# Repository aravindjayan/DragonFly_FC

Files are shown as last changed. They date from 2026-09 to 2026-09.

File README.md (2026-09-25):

# DragonFly Flight Controller

DragonFly Flight Controller is an open hardware, low-cost flight controller PCB and experimentation platform for UAV, drone, and embedded systems prototyping. This cost-optimised design uses a two-layer PCB, a budget-conscious bill of materials (BOM), and readily fabricated manufacturing files. Prototype boards were fabricated using the LionCircuits MII service.

The KiCad design targets broad sensor compatibility: it supports most ST LSM6D-series IMUs, while the magnetometer footprint accommodates QMC5883, HMC5883, MMC5983, and IST8310 parts. This makes DragonFly a flexible platform for flight-control experiments, sensor evaluation, and affordable PCB prototyping.

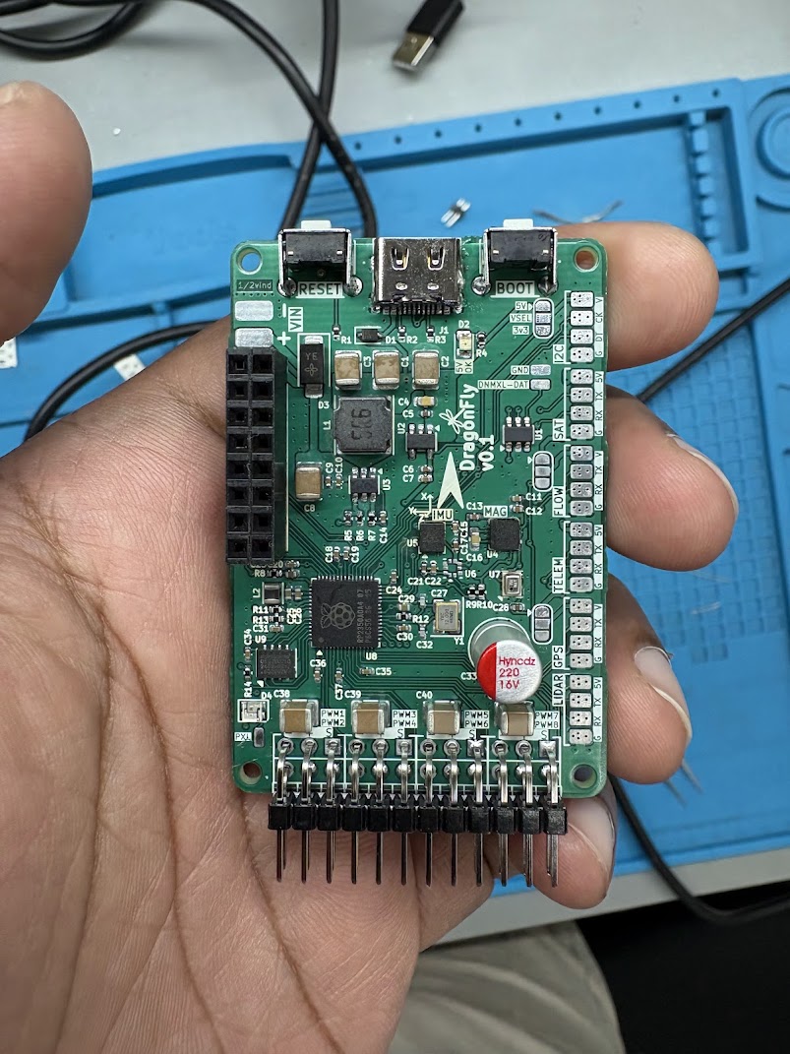
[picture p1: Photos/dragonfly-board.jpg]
Assembled DragonFly flight controller


## Repository contents

- `KiCad/Source/` — editable V0.1 board, hierarchical schematic sheets, and project settings.
- `KiCad/Production/` — PCB and project settings for the released `withRibs` manufacturing revision used to generate the production Gerbers.
- `Manufacturing/Gerbers/` — production Gerber layers, drill files, drill maps, and KiCad job file.
- `Photos/` — photo of the assembled PCB.

## Fabrication

Send all files in `Manufacturing/Gerbers/` to your PCB fabricator as one fabrication package. The set includes front and back copper, solder mask, silkscreen, paste, board outline, plated and non-plated drill files, drill maps, and the Gerber job file. Confirm your fabricator accepts these Gerber formats and review the generated previews before ordering.

The released board includes an external rib frame (`withRibs`) for fabrication. Use the matching board in `KiCad/Production/` when reviewing this manufacturing package. `KiCad/Source/` retains the editable source project from the main V0.1 design directory.

## Opening the design

Open `KiCad/Source/dragonfly_v0_1.kicad_pro` in KiCad to work with the source design. Open `KiCad/Production/Dragonfly_v0-1_Ribs.kicad_pcb` to inspect the exact released manufacturing board.

## Revision notes

The production files are from the V0.1 `withRibs` release. The original release notes describe it as adding an external rib frame for improved fabrication. Review electrical design, clearances, and fabrication outputs independently before manufacturing or flight use.

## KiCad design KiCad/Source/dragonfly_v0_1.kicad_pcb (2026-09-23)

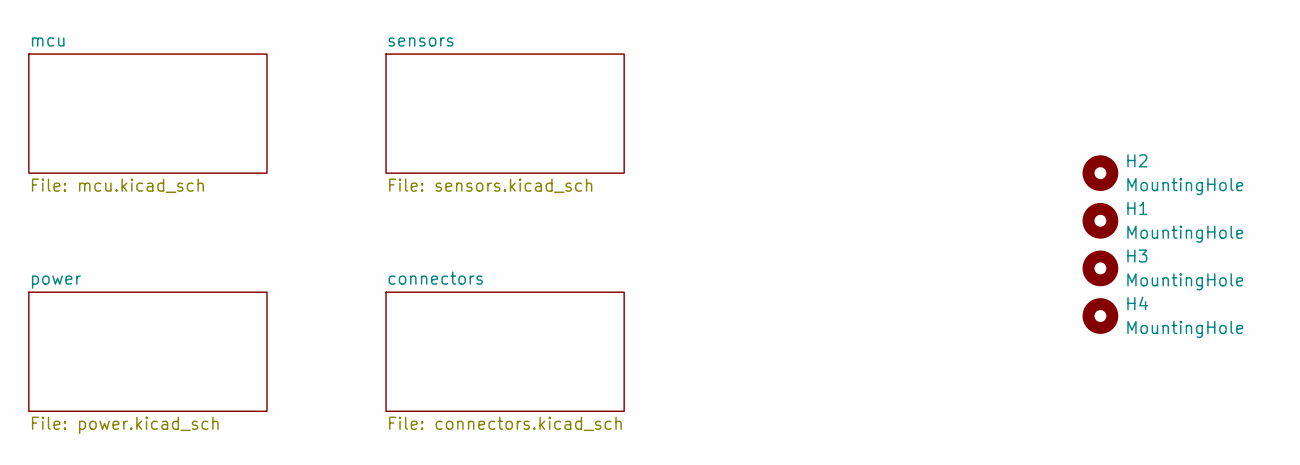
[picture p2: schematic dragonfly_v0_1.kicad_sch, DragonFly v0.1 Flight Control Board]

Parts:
H1, H2, H3, H4: MountingHole; MountingHole_2.2mm_M2_ISO14580

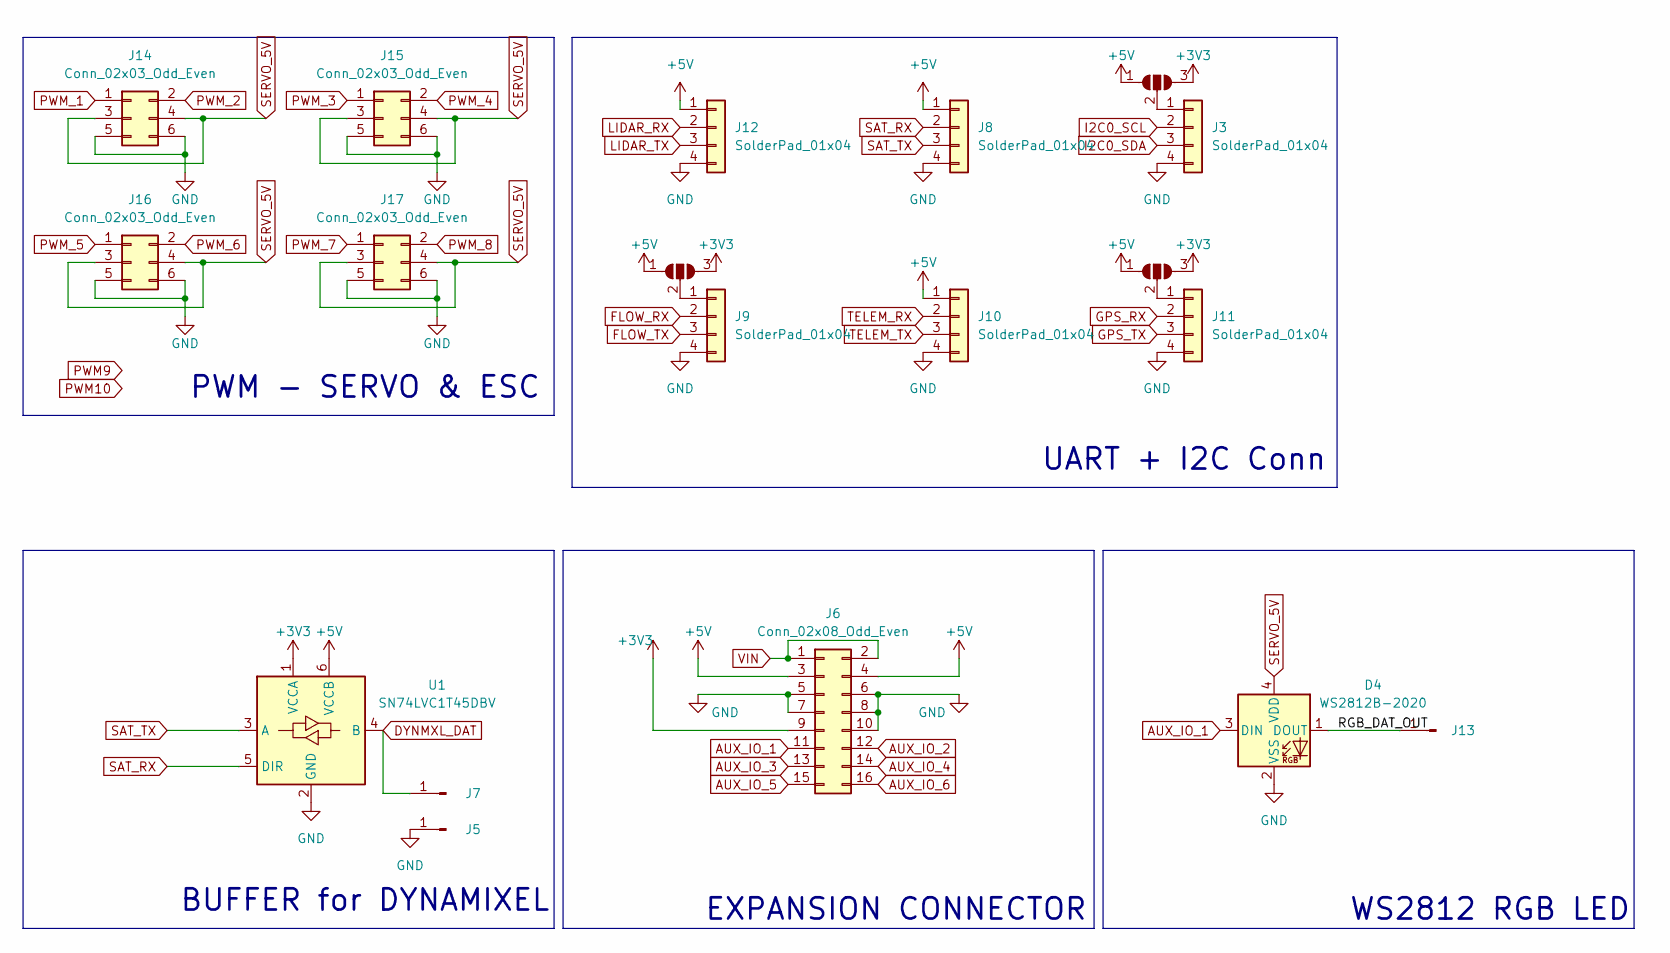
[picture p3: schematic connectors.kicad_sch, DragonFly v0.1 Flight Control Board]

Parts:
D4: WS2812B-2020; LED_WS2812B-2020_PLCC4_2.0x2.0mm
J3, J8, J9, J10, J11, J12: SolderPad_01x04; 4pad_doubleSide_rect_1.7x2mm
J5, J7, J13: SolderPad; SolderWirePad_1x01_SMD_1x2mm
J6: Conn_02x08_Odd_Even; PinSocket_2x08_P2.54mm_Vertical
J14, J15, J16, J17: Conn_02x03_Odd_Even; dragonfly_conn_2x3_graphics
JP1, JP2, JP3: SolderJumper_3_Open; SolderJumper-3_P1.3mm_Open_RoundedPad1.0x1.5mm
U1: SN74LVC1T45DBV; SOT-23-6

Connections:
+3V3: J6.9, JP1.3 (B), JP2.3 (B), JP3.3 (B), U1.1 (VCCA); also elsewhere on the board
+5V: J6.3, J6.4, J8.1, J10.1, J12.1, JP1.1 (A), JP2.1 (A), JP3.1 (A), U1.6 (VCCB); also elsewhere on the board
/connectors/RGB_DAT_OUT: D4.1 (DOUT), J13.1
AUX_IO_1: D4.3 (DIN), J6.11; also elsewhere on the board
AUX_IO_2: J6.12; also elsewhere on the board
AUX_IO_3: J6.13; also elsewhere on the board
AUX_IO_4: J6.14; also elsewhere on the board
AUX_IO_5: J6.15; also elsewhere on the board
AUX_IO_6: J6.16; also elsewhere on the board
DYNMXL_DAT: J7.1, U1.4 (B)
FLOW_RX: J9.2; also elsewhere on the board
FLOW_TX: J9.3; also elsewhere on the board
GND: D4.2 (VSS), J3.4, J5.1, J6.5, J6.6, J6.7, J6.8, J6.10, J8.4, J9.4, J10.4, J11.4, J12.4, J14.5, J14.6, J15.5, J15.6, J16.5, J16.6, J17.5, J17.6, U1.2 (GND); also elsewhere on the board
GPS_RX: J11.2; also elsewhere on the board
GPS_TX: J11.3; also elsewhere on the board
I2C0_SCL: J3.2; also elsewhere on the board
I2C0_SDA: J3.3; also elsewhere on the board
LIDAR_RX: J12.2; also elsewhere on the board
LIDAR_TX: J12.3; also elsewhere on the board
unnamed: J3.1, JP1.2 (C)
unnamed: J9.1, JP2.2 (C)
unnamed: J11.1, JP3.2 (C)
PWM_1: J14.1; also elsewhere on the board
PWM_2: J14.2; also elsewhere on the board
PWM_3: J15.1; also elsewhere on the board
PWM_4: J15.2; also elsewhere on the board
PWM_5: J16.1; also elsewhere on the board
PWM_6: J16.2; also elsewhere on the board
PWM_7: J17.1; also elsewhere on the board
PWM_8: J17.2; also elsewhere on the board
SAT_RX: J8.2, U1.5 (DIR); also elsewhere on the board
SAT_TX: J8.3, U1.3 (A); also elsewhere on the board
SERVO_5V: D4.4 (VDD), J14.3, J14.4, J15.3, J15.4, J16.3, J16.4, J17.3, J17.4; also elsewhere on the board
TELEM_RX: J10.2; also elsewhere on the board
TELEM_TX: J10.3; also elsewhere on the board
VIN: J6.1, J6.2; also elsewhere on the board

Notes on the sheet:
UART + I2C Conn
EXPANSION CONNECTOR
PWM - SERVO & ESC
WS2812 RGB LED
BUFFER for DYNAMIXEL

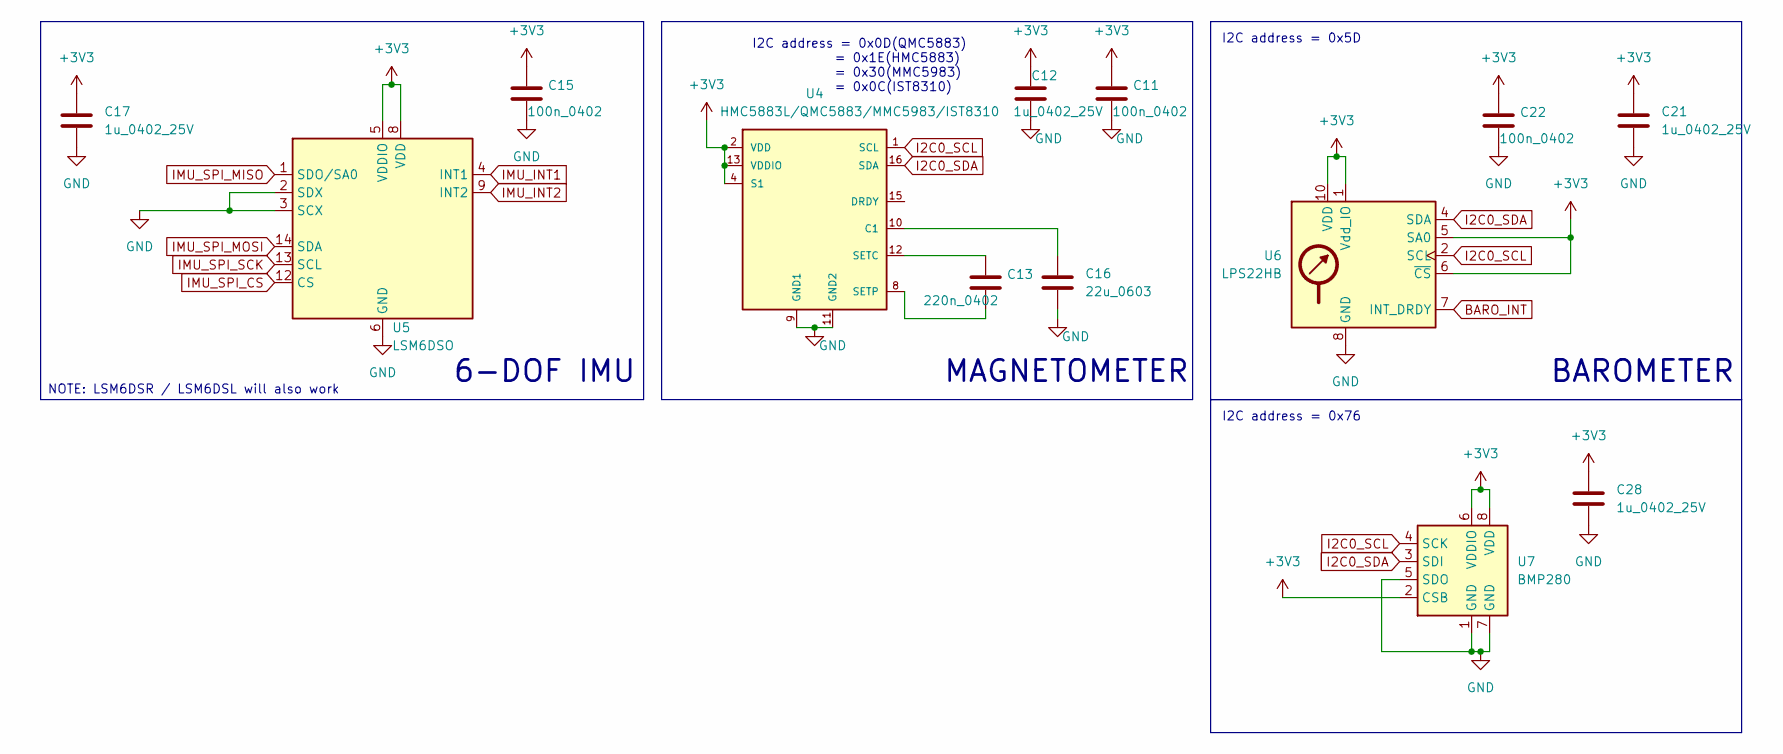
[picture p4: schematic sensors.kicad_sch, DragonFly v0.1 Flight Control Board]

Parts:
C11, C15, C22: 100n_0402; C_0402_1005Metric
C12, C17, C21, C28: 1u_0402_25V; C_0402_1005Metric
C13: 220n_0402; C_0402_1005Metric
C16: 22u_0603; C_0603_1608Metric
U4: HMC5883L/QMC5883/MMC5983/IST8310; HMC5883L
U5: LSM6DSO; LGA-14_3x2.5mm_P0.5mm_LayoutBorder3x4y
U6: LPS22HB; LPS22_HLGA10_SNAPEDA
U7: BMP280; BMP280_Bosch_LGA-8_2x2.5mm_P0.65mm_ClockwisePinNumbering

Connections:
+3V3: C11.1, C12.1, C15.1, C17.1, C21.1, C22.1, C28.1, U4.2 (VDD), U4.4 (S1), U4.13 (VDDIO), U5.5 (VDDIO), U5.8 (VDD), U6.1 (Vdd_IO), U6.5 (SA0), U6.6 (~CS), U6.10 (VDD), U7.2 (CSB), U7.6 (VDDIO), U7.8 (VDD); also elsewhere on the board
BARO_INT: U6.7 (INT_DRDY)
GND: C11.2, C12.2, C15.2, C16.2, C17.2, C21.2, C22.2, C28.2, U4.9 (GND1), U4.11 (GND2), U5.2 (SDX), U5.3 (SCX), U5.6 (GND), U5.7 (GND), U6.3 (GND), U6.8 (GND), U6.9 (GND), U7.1 (GND), U7.5 (SDO), U7.7 (GND); also elsewhere on the board
I2C0_SCL: U4.1 (SCL), U6.2 (SCL), U7.4 (SCK); also elsewhere on the board
I2C0_SDA: U4.16 (SDA), U6.4 (SDA), U7.3 (SDI); also elsewhere on the board
IMU_INT1: U5.4 (INT1)
IMU_INT2: U5.9 (INT2)
IMU_SPI_CS: U5.12 (CS); also elsewhere on the board
IMU_SPI_MISO: U5.1 (SDO/SA0); also elsewhere on the board
IMU_SPI_MOSI: U5.14 (SDA); also elsewhere on the board
IMU_SPI_SCK: U5.13 (SCL); also elsewhere on the board
unnamed: C16.1, U4.10 (C1)
unnamed: C13.1, U4.12 (SETC)
unnamed: C13.2, U4.8 (SETP)

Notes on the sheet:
BAROMETER
NOTE: LSM6DSR / LSM6DSL will also work
I2C address = 0x0D(QMC5883) = 0x1E(HMC5883) = 0x30(MMC5983) = 0x0C(IST8310)
I2C address = 0x76
6-DOF IMU
MAGNETOMETER
I2C address = 0x5D

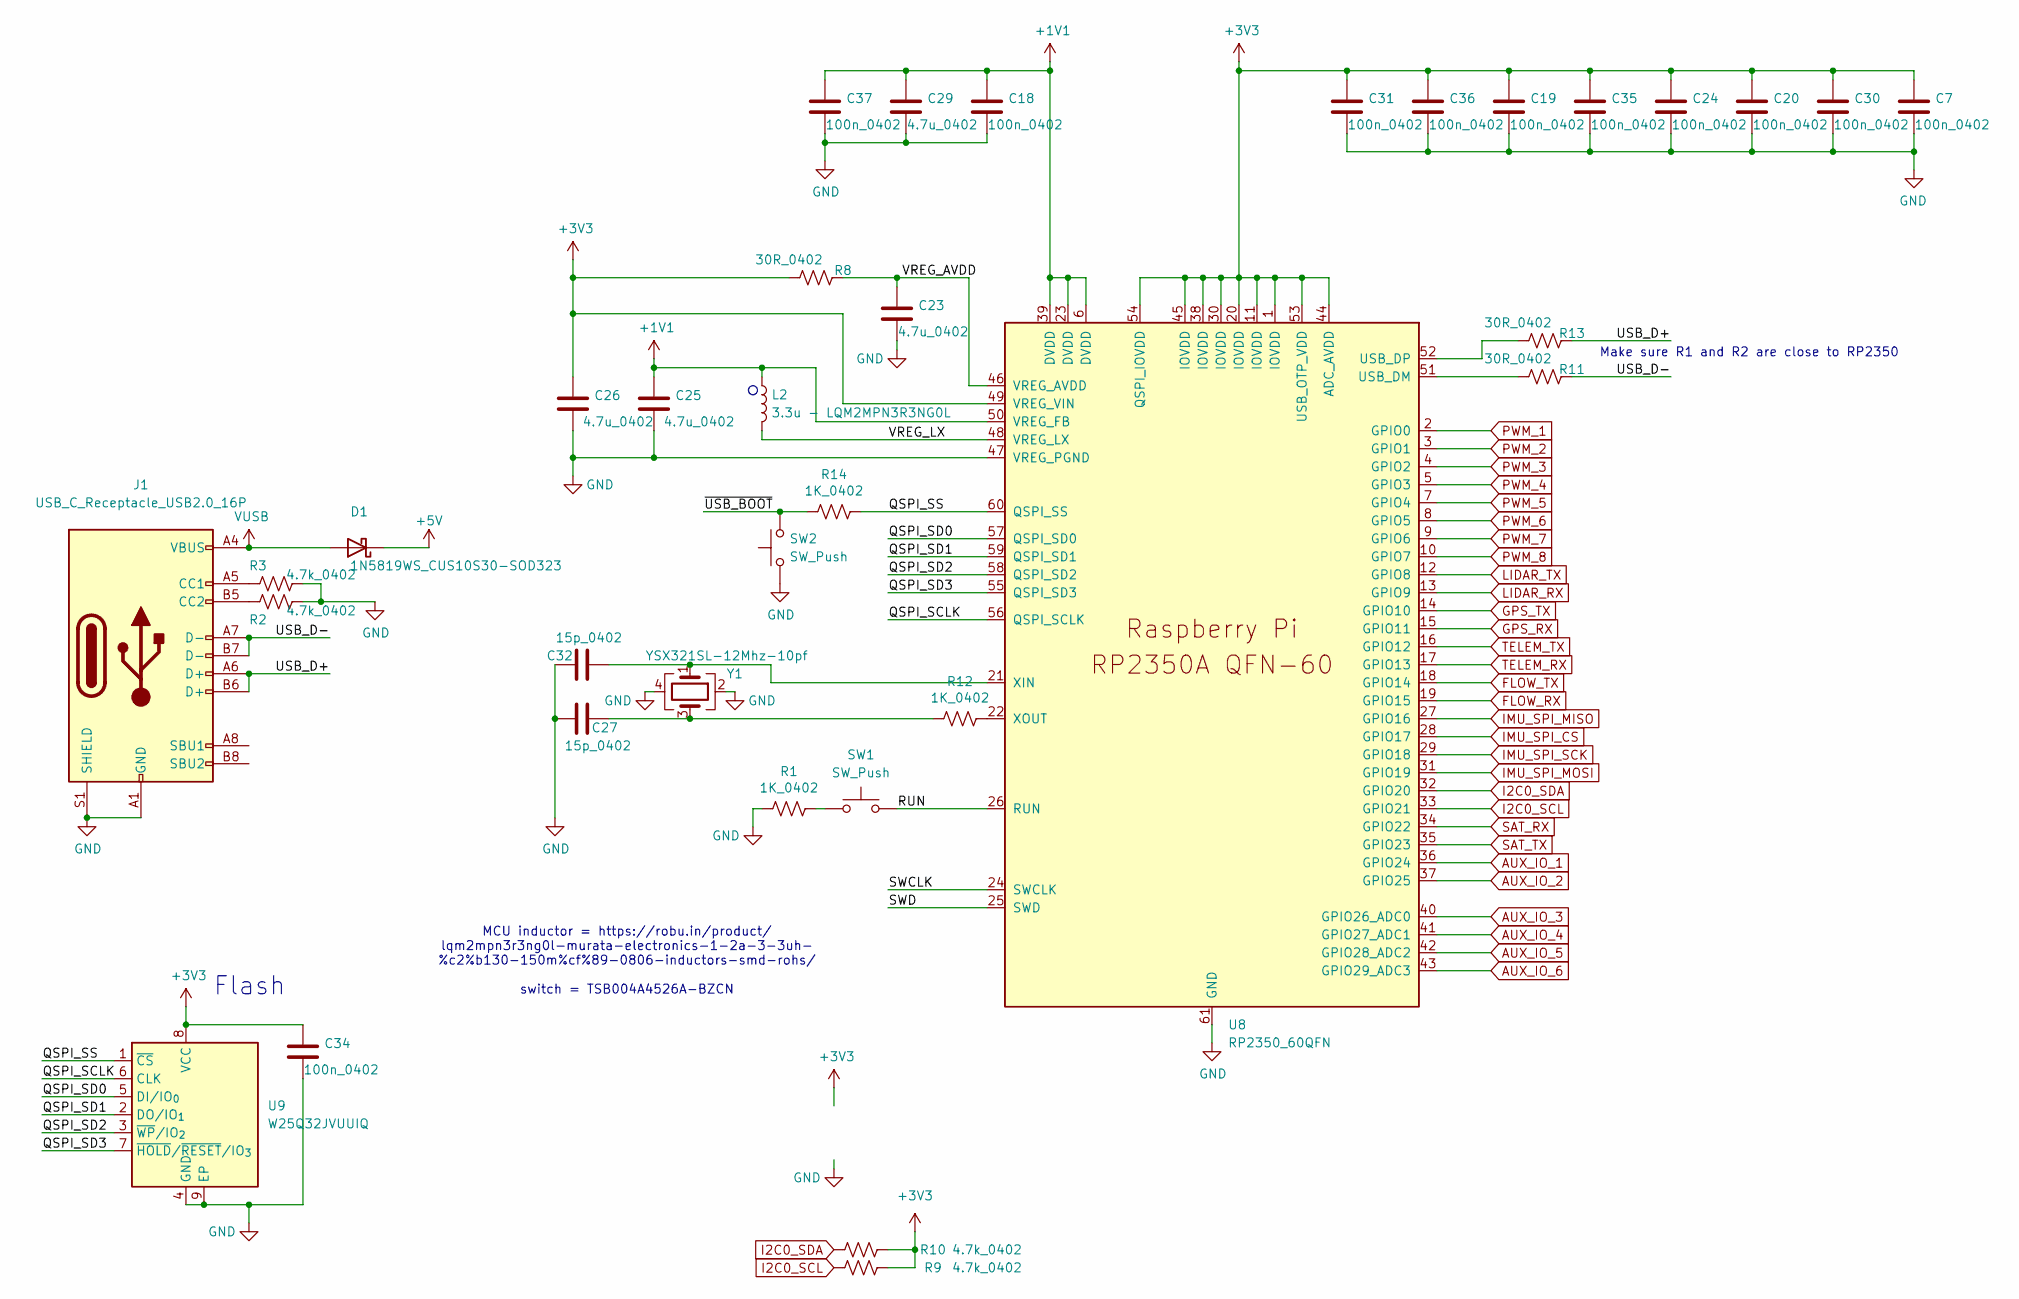
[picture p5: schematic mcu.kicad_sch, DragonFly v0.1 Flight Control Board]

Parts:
C7, C18, C19, C20, C24, C30, C31, C34, C35, C36, C37: 100n_0402; C_0402_1005Metric
C23, C29: 4.7u_0402; C_0402_1005Metric
C25, C26: 4.7u_0402; C_0402_SmallPads
C27, C32: 15p_0402; C_0402_1005Metric
D1: 1N5819WS_CUS10S30-SOD323; D_SOD-323
J1: USB_C_Receptacle_USB2.0_16P; USB_C_Receptacle_XKB_U262-16XN-4BVC11
L2: 3.3u - LQM2MPN3R3NG0L; L_Murata_DFE201610P
R1, R12, R14: 1K_0402; R_0402_1005Metric
R2, R3, R9, R10: 4.7k_0402; R_0402_1005Metric
R8, R11, R13: 30R_0402; R_0402_1005Metric
SW1, SW2: SW_Push; rightAngle_Switch_MJTP1117
U8: RP2350_60QFN; QFN-60-1EP_7x7mm_P0.4mm_EP3.4x3.4mm_ThermalVias_RP2350
U9: W25Q32JVUUIQ; Winbond_USON-8-2EP_3x4mm_P0.8mm_EP0.2x0.8mm
Y1: YSX321SL-12Mhz-10pf; Crystal_SMD_3225-4Pin_3.2x2.5mm

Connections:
+1V1: C18.1, C25.1, C29.1, C37.1, L2.1, U8.6 (DVDD), U8.23 (DVDD), U8.39 (DVDD), U8.50 (VREG_FB)
+3V3: C7.1, C19.1, C20.1, C24.1, C26.1, C30.1, C31.1, C34.1, C35.1, C36.1, R8.2, R9.1, R10.1, U8.1 (IOVDD), U8.11 (IOVDD), U8.20 (IOVDD), U8.30 (IOVDD), U8.38 (IOVDD), U8.44 (ADC_AVDD), U8.45 (IOVDD), U8.49 (VREG_VIN), U8.53 (USB_OTP_VDD), U8.54 (QSPI_IOVDD), U9.8 (VCC); also elsewhere on the board
+5V: D1.1 (K); also elsewhere on the board
/mcu/QSPI_SCLK: U8.56 (QSPI_SCLK), U9.6 (CLK)
/mcu/QSPI_SD0: U8.57 (QSPI_SD0), U9.5 (DI/IO_{0})
/mcu/QSPI_SD1: U8.59 (QSPI_SD1), U9.2 (DO/IO_{1})
/mcu/QSPI_SD2: U8.58 (QSPI_SD2), U9.3 (~WP/IO_{2})
/mcu/QSPI_SD3: U8.55 (QSPI_SD3), U9.7 (~HOLD/~RESET/IO_{3})
/mcu/QSPI_SS: R14.1, U8.60 (QSPI_SS), U9.1 (~CS)
/mcu/RUN: SW1.2, U8.26 (RUN)
/mcu/SWCLK: U8.24 (SWCLK)
/mcu/SWD: U8.25 (SWD)
/mcu/USB_D+: J1.A6 (D+), J1.B6 (D+), R13.1
/mcu/USB_D-: J1.A7 (D-), J1.B7 (D-), R11.1
/mcu/VREG_AVDD: C23.1, R8.1, U8.46 (VREG_AVDD)
/mcu/VREG_LX: L2.2, U8.48 (VREG_LX)
/mcu/~USB_BOOT: R14.2, SW2.2
AUX_IO_1: U8.36 (GPIO24); also elsewhere on the board
AUX_IO_2: U8.37 (GPIO25); also elsewhere on the board
AUX_IO_3: U8.40 (GPIO26_ADC0); also elsewhere on the board
AUX_IO_4: U8.41 (GPIO27_ADC1); also elsewhere on the board
AUX_IO_5: U8.42 (GPIO28_ADC2); also elsewhere on the board
AUX_IO_6: U8.43 (GPIO29_ADC3); also elsewhere on the board
FLOW_RX: U8.19 (GPIO15); also elsewhere on the board
FLOW_TX: U8.18 (GPIO14); also elsewhere on the board
GND: C7.2, C18.2, C19.2, C20.2, C23.2, C24.2, C25.2, C26.2, C27.2, C29.2, C30.2, C31.2, C32.2, C34.2, C35.2, C36.2, C37.2, J1.A1 (GND), J1.A12 (GND), J1.B1 (GND), J1.B12 (GND), J1.S1 (SHIELD), R1.2, R2.1, R3.1, SW2.1, U8.47 (VREG_PGND), U8.61 (GND), U9.4 (GND), U9.9 (EP), Y1.2, Y1.4; also elsewhere on the board
GPS_RX: U8.15 (GPIO11); also elsewhere on the board
GPS_TX: U8.14 (GPIO10); also elsewhere on the board
I2C0_SCL: R9.2, U8.33 (GPIO21); also elsewhere on the board
I2C0_SDA: R10.2, U8.32 (GPIO20); also elsewhere on the board
IMU_SPI_CS: U8.28 (GPIO17); also elsewhere on the board
IMU_SPI_MISO: U8.27 (GPIO16); also elsewhere on the board
IMU_SPI_MOSI: U8.31 (GPIO19); also elsewhere on the board
IMU_SPI_SCK: U8.29 (GPIO18); also elsewhere on the board
LIDAR_RX: U8.13 (GPIO9); also elsewhere on the board
LIDAR_TX: U8.12 (GPIO8); also elsewhere on the board
unnamed: C27.1, R12.2, Y1.3
unnamed: J1.A5 (CC1), R3.2
unnamed: J1.B5 (CC2), R2.2
unnamed: R1.1, SW1.1
unnamed: R11.2, U8.51 (USB_DM)
unnamed: R13.2, U8.52 (USB_DP)
unnamed: C32.1, U8.21 (XIN), Y1.1
unnamed: R12.1, U8.22 (XOUT)
PWM_1: U8.2 (GPIO0); also elsewhere on the board
PWM_2: U8.3 (GPIO1); also elsewhere on the board
PWM_3: U8.4 (GPIO2); also elsewhere on the board
PWM_4: U8.5 (GPIO3); also elsewhere on the board
PWM_5: U8.7 (GPIO4); also elsewhere on the board
PWM_6: U8.8 (GPIO5); also elsewhere on the board
PWM_7: U8.9 (GPIO6); also elsewhere on the board
PWM_8: U8.10 (GPIO7); also elsewhere on the board
SAT_RX: U8.34 (GPIO22); also elsewhere on the board
SAT_TX: U8.35 (GPIO23); also elsewhere on the board
TELEM_RX: U8.17 (GPIO13); also elsewhere on the board
TELEM_TX: U8.16 (GPIO12); also elsewhere on the board
VUSB: D1.2 (A), J1.A4 (VBUS), J1.A9 (VBUS), J1.B4 (VBUS), J1.B9 (VBUS)

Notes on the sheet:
Make sure R1 and R2 are close to RP2350
MCU inductor = https://robu.in/product/ lqm2mpn3r3ng0l-murata-electronics-1-2a-3-3uh- %c2%b130-150m%cf%89-0806-inductors-smd-rohs/ switch = TSB004A4526A-BZCN
Flash

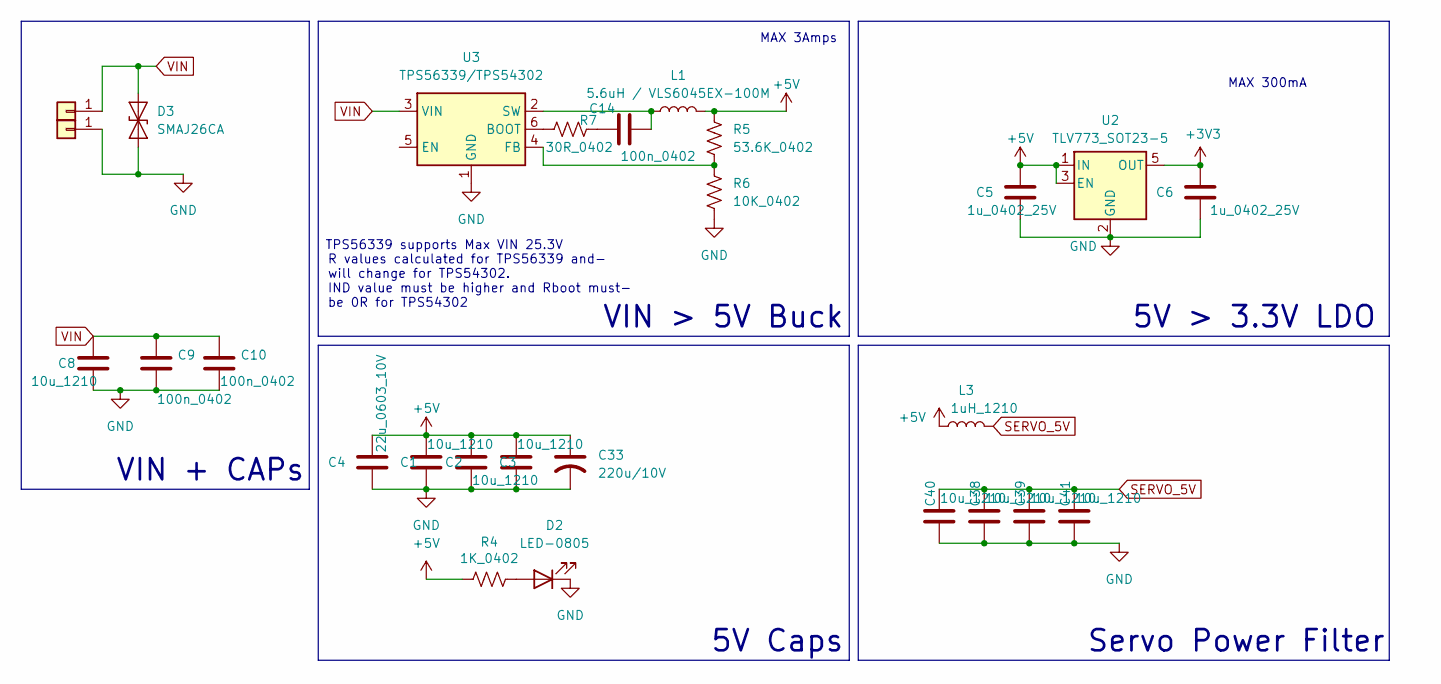
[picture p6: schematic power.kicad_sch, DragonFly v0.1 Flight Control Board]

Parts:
C1, C2, C3, C8, C38, C39, C40, C41: 10u_1210; C_1210_3225Metric
C4: 22u_0603_10V; C_0603_1608Metric
C5, C6: 1u_0402_25V; C_0402_1005Metric
C9, C10, C14: 100n_0402; C_0402_1005Metric
C33: 220u/10V; C_Radial_D6.3mm_H5.0mm_P2.50mm
D2: LED-0805; LED_0805_2012Metric
D3: SMAJ26CA; D_SMA
J2, J4: SolderPad; SolderWirePad_1x01_SMD_2x4mm
L1: 5.6uH / VLS6045EX-100M; L_Sunlord_SWPA6045S
L3: 1uH_1210; L_1210_3225Metric_Pad1.42x2.65mm_HandSolder
R4: 1K_0402; R_0402_1005Metric
R5: 53.6K_0402; R_0402_1005Metric
R6: 10K_0402; R_0402_1005Metric
R7: 30R_0402; R_0402_1005Metric
U2: TLV773_SOT23-5; SOT-23-5
U3: TPS56339/TPS54302; SOT-23-6

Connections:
+3V3: C6.2, U2.5 (OUT); also elsewhere on the board
+5V: C1.1, C2.1, C3.1, C4.2, C5.2, C33.1, L1.2, L3.1, R4.2, R5.2, U2.1 (IN), U2.3 (EN); also elsewhere on the board
GND: C1.2, C2.2, C3.2, C4.1, C5.1, C6.1, C8.2, C9.2, C10.2, C33.2, C38.2, C39.2, C40.2, C41.2, D2.1 (K), D3.1 (A1), J2.1, R6.1, U2.2 (GND), U3.1 (GND); also elsewhere on the board
unnamed: C14.1, R7.2
unnamed: D2.2 (A), R4.1
unnamed: R7.1, U3.6 (BOOT)
unnamed: R5.1, R6.2, U3.4 (FB)
unnamed: C14.2, L1.1, U3.2 (SW)
SERVO_5V: C38.1, C39.1, C40.1, C41.1, L3.2; also elsewhere on the board
VIN: C8.1, C9.1, C10.1, D3.2 (A2), J4.1, U3.3 (VIN); also elsewhere on the board

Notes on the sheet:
5V Caps
Servo Power Filter
R values calculated for TPS56339 and- will change for TPS54302. IND value must be higher and Rboot must- be 0R for TPS54302
5V > 3.3V LDO
MAX 3Amps
VIN > 5V Buck
TPS56339 supports Max VIN 25.3V
MAX 300mA
VIN + CAPs

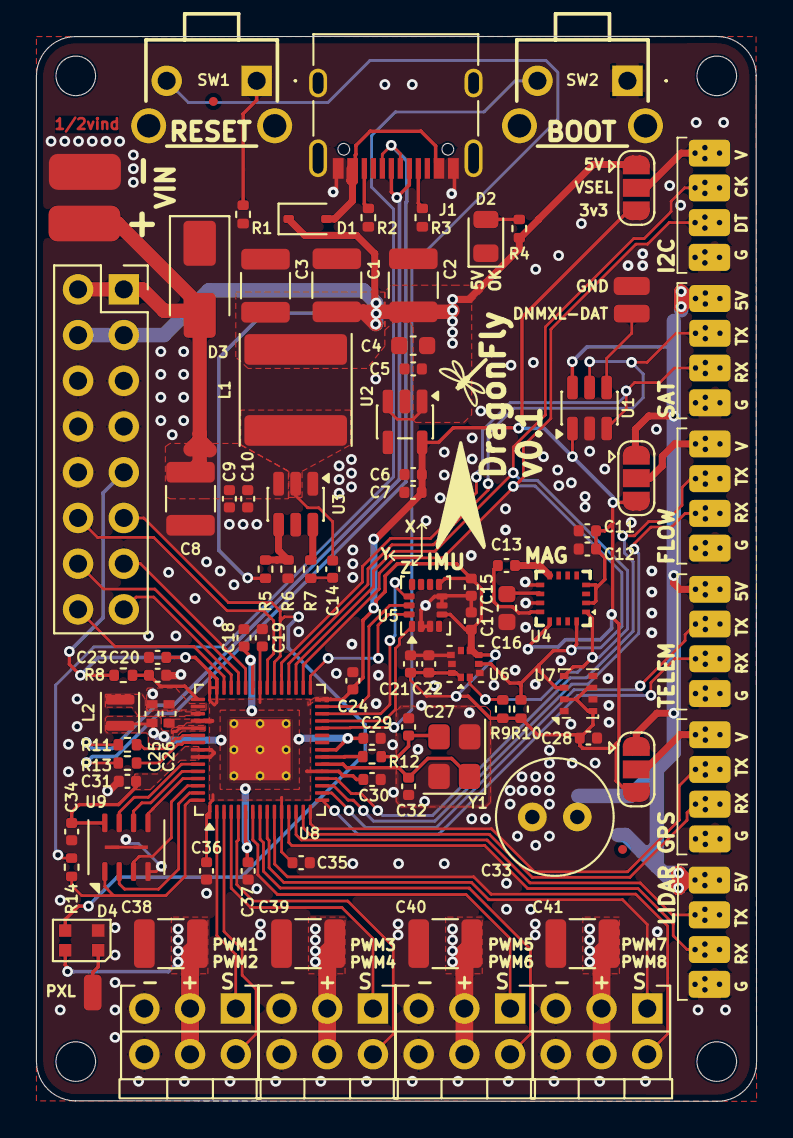
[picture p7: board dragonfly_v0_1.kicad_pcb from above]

Board: 2 copper layers, 40.0 x 59.2 mm, 98 parts (1 on the bottom side), 70 nets.
